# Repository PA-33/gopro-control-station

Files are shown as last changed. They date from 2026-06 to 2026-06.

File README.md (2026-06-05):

# GoPro Control Station

A complete remote control station for a GoPro Hero camera.

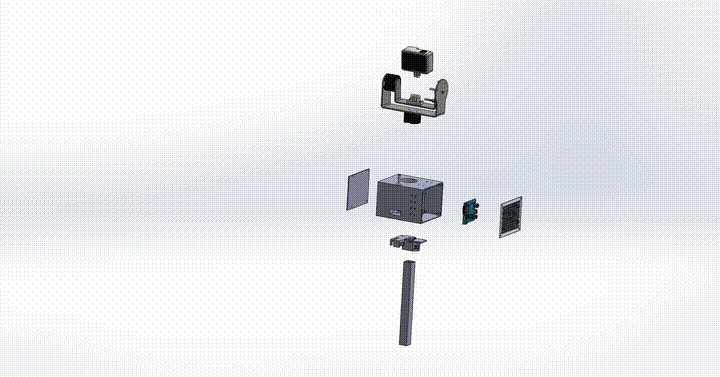
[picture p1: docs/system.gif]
System demo


The system combines a two-axis motorised mount (so the camera can be aimed
without touching it) with full remote control of the camera itself
(shutter, mode, gallery, live HDMI preview). Everything is driven by a
single ESP32-S3 board running closed-loop FOC for the motors, BLE for
the camera commands, and an HTTPS web server for the user interface.

## Features

- Two-axis motorised mount with absolute angular position
- Magnetic encoders for accurate, drift-free positioning
- Soft-limits with automatic end-stop calibration
- Stall protection with auto-recovery (re-centres the motor on re-enable)
- BLE control of the GoPro (shutter, mode, sleep, keep-alive)
- Wi-Fi proxy to the GoPro REST API (gallery, thumbnails, downloads)
- Browser-based live HDMI preview via a USB-C capture card
- Self-signed HTTPS server with embedded certificate
- Persistent configuration and calibration in NVS
- Status LED strip for camera, motors, recording state and battery

The user interacts with the system through two parallel channels:

- **Physical panel** — five buttons (M1+, M1-, M2+, M2-, shutter) and a
  7-LED status strip.
- **Web interface** — served on the station's own Wi-Fi access point:
  control, gallery, live HDMI preview and configuration in a
  mobile-friendly UI.

## Repository layout

```
gopro-control-station/
├── platformio.ini              PlatformIO build configuration
├── README.md
├── LICENSE
│
├── src/                        Firmware sources (Arduino + ESP-IDF)
│   ├── bridge_main.cpp         setup() / loop() / status LEDs
│   ├── bridge_foc.cpp/.h       motor control, buttons, calibration
│   ├── bridge_current.cpp/.h   current sensing + stall detection
│   ├── bridge_ble.cpp/.h       NimBLE client (OpenGoPro)
│   ├── bridge_wifi.cpp/.h      Wi-Fi AP + STA + watchdog
│   ├── bridge_https.cpp/.h     TLS web server + REST proxy
│   ├── bridge_server.cpp/.h    plain HTTP (cert download only)
│   ├── bridge_config.cpp/.h    persistent configuration (NVS)
│   ├── bridge_led.h            LED constants
│   └── ssl_cert.h              embedded TLS certificate (auto-generated)
│
├── data/
│   └── index.html              single-page web UI (served from LittleFS)
│
├── certs/                      TLS certificate + regeneration toolchain
│   ├── bridge_cert.pem
│   ├── bridge_key.pem
│   ├── openssl.cnf
│   ├── generate.bat            Windows: regenerate cert + key + header
│   └── make_header.py          convert PEM into src/ssl_cert.h
│
├── hardware/
│   ├── cad/
│   │   ├── source/             CAD source files
│   │   └── exports/            exported 3D-printable files
│   └── kicad/
│       ├── gimbal_driver_board/ electrical schematic + PCB sources
│       └── exports/            generated manufacturing files
│
└── docs/
    ├── user_manual.pdf           end-user manual
    └── Mode_d_emploi.pdf         end-user manual (French)
```

## Quick start

### 1. Build and flash the firmware

```bash
# Firmware
pio run -e esp32-s3-bridge -t upload

# Web UI (LittleFS image)
pio run -e esp32-s3-bridge -t uploadfs

# Watch the boot log
pio device monitor -e esp32-s3-bridge
```

A clean first boot prints, in order: PCF8574 ready, FOC init OK x2,
Wi-Fi AP up, BLE connected to the camera, HTTPS server started, Wi-Fi
STA connected to the GoPro. See `docs/repport.tex` §5.5 for the
reference serial log.

### 2. Connect

1. Join the Wi-Fi network `GoPro-Bridge` (default password `gopro1234`).
2. Open `https://192.168.4.1` in a browser.
3. Accept the security warning, or download the certificate from the
   *Config* tab and install it to make the warning go away.

### 3. Adapt to your own GoPro

No source edit is required. After the first boot, go to the *Config* tab
in the web UI, replace the GoPro Wi-Fi SSID and password with the ones
printed on your camera (*Connections / Connect Device / GoPro App*),
*Save*, and reboot.

## Documentation

- **`docs/mode_emploi.tex`** — end-user manual (French). Buttons, LEDs,
  web interface, calibration procedure.
- **`hardware/cad/`** — CAD sources and exports for the mechanical
  parts. Print settings and assembly order are documented in §3 of the
  report.
- **`hardware/kicad/`** — full electrical schematic and PCB project. The pin
  assignments are also reproduced in §4 of the report and are
  hard-coded in the firmware (see `src/bridge_foc.cpp`).

## Regenerating the TLS certificate

The repository ships with a self-signed development certificate that
works out of the box. For any deployment where the local network is not
trusted, regenerate it:

```bash
cd certs
generate.bat            # Windows
# POSIX equivalent: see docs/repport.tex Appendix D
```

Then re-flash the firmware. Every client that already trusted the
previous certificate has to install the new one (web UI, *Config* tab).

## Hardware overview

- **MCU**: ESP32-S3 (`esp32-s3-devkitc-1`), 8 MB flash, no PSRAM.
- **Motors**: 2x BLDC (11 pole pairs), each driven by a DRV8313.
- **Encoders**: 2x AS5048A magnetic absolute encoders (SPI / HSPI bus).
- **Buttons**: 5x momentary, multiplexed through a PCF8574T (I2C).
- **Current sense**: 2x INA180A1 with 50 mOhm shunts, read on ADC2.
- **Indicators**: WS2815 strip, 7 LEDs.
- **Camera**: GoPro Hero (any model compatible with the OpenGoPro BLE
  specification) with the official Media Mod for HDMI output.
- **HDMI capture**: any UVC-class USB-C card (UGREEN 15389 is
  auto-selected by the web UI).

## License

This project is released under the [MIT License](LICENSE). You can use,
modify and redistribute it freely, including for commercial purposes,
provided that the copyright notice and the license text are kept.

## Acknowledgements

Built on top of [SimpleFOC](https://docs.simplefoc.com/),
[NimBLE-Arduino](https://github.com/h2zero/NimBLE-Arduino),
[ESPAsyncWebServer](https://github.com/mathieucarbou/ESPAsyncWebServer),
and the [pioarduino fork](https://github.com/pioarduino/platform-espressif32)
of `platform-espressif32`. Camera control follows the
[OpenGoPro](https://gopro.github.io/OpenGoPro/) specification.

## Context

This project was developed by Pierre Adamini and Florian Klein as part of
the Assistive Technology Challenge at EPFL (2026).

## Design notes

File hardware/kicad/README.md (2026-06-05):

# KiCad project

Put the full KiCad source project here:

- `*.kicad_pro`
- `*.kicad_sch`
- `*.kicad_pcb`

Optional, only if you create local libraries later:

- `symbols/` for custom symbol libraries
- `footprints/` for custom footprint libraries

Use `exports/` for generated outputs only:

- Gerbers
- drill files
- PDF schematics
- BOM / pick-and-place files

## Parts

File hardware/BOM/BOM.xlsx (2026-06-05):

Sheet: Pièces usinées
PIÈCES USINÉES — Bill of Materials
Pièces imprimées 3D
Pièce | Quantité | Matériau
support_gopro | 1 | TPU | #VALUE!
limite | 2 | PLA/PETG | #VALUE!
casing | 1 | PLA/PETG | #VALUE!
grille_aeration | 1 | PLA/PETG | #VALUE!
couvercle_batterie | 1 | PLA/PETG | #VALUE!
adaptateur_casing_barre | 1 | PETG | #VALUE!
bearing support | 1 | PLA/PETG | #VALUE!
Chaise manuelle
Pièce | Quantité | Matériau
adaptateur_vertical | 1 | PETG | #VALUE!
adaptateur_horizontal | 1 | PETG | #VALUE!
Chaise motorisée
Pièce | Quantité | Matériau
adaptateur_chaise_motorisee | 1 | PETG | #VALUE!
Table
Pièce | Quantité | Matériau
pied_table | 1 | PLA/PETG | #VALUE!
Pièces découpées laser / PETG 100% remplissage
Pièce | Quantité | Matériau
support_gopro_int | 1 | Alu/PETG | #VALUE!
support_gopro_ext | 1 | Alu/PETG | #VALUE!

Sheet: BOM_PCB
PCB BILL OF MATERIALS
Reference | Qty | Value | DNP | Excl. Board | Footprint | Datasheet | URL Mouser
C1,C3 | 2 | 10uF |  |  | Capacitor_SMD:C_0805_2012Metric_Pad1.18x1.45mm_HandSolder | ~ | https://www.mouser.ch/ProductDetail/Murata-Electronics/GRM21BR61C106KE15L?qs=vS1sKHMaE9UZ7Oz%252BS7dCHg%3D%3D
C2,C4,C5,C8,C9,C11,C12,C13,C18,C19,C21,C22 | 12 | 100nF |  |  | Capacitor_SMD:C_0805_2012Metric_Pad1.18x1.45mm_HandSolder | ~ | https://www.mouser.ch/ProductDetail/KEMET/C0805C104K5RACTU?qs=ED%252B2xvMfDz1vOybjYDNIsA%3D%3D
C6,C16 | 2 | 10nF |  |  | Capacitor_SMD:C_0805_2012Metric_Pad1.18x1.45mm_HandSolder | ~ | https://www.mouser.ch/c/passive-components/capacitors/ceramic-capacitors/mlccs-multilayer-ceramic-capacitors/multilayer-ceramic-capacitors-mlcc-smd-smt/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
C7,C17 | 2 | 470nF |  |  | Capacitor_SMD:C_0805_2012Metric_Pad1.18x1.45mm_HandSolder | ~ | https://www.mouser.ch/c/passive-components/capacitors/ceramic-capacitors/mlccs-multilayer-ceramic-capacitors/multilayer-ceramic-capacitors-mlcc-smd-smt/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
C10,C20 | 2 | 100uF |  |  | Capacitor_THT:CP_Radial_D10.0mm_P5.00mm | ~ | https://www.mouser.ch/ProductDetail/Panasonic/ECA-1CM101?qs=fcM5arftASsgt75dWf2hGA%3D%3D
C14,C15 | 2 | 470uF |  |  | Capacitor_THT:CP_Radial_D10.0mm_P5.00mm | ~ | https://www.mouser.ch/c/passive-components/capacitors/aluminum-electrolytic-capacitors/aluminum-electrolytic-capacitors-radial-leaded/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
D1 | 1 | 1N5819HW-7-F |  |  | LED_SMD:LED_0805_2012Metric_Pad1.15x1.40mm_HandSolder | https://datasheet.lcsc.com/lcsc/2204281430_Guangdong-Hottech-1N5819WS_C191023.pdf | https://www.mouser.ch/ProductDetail/Diodes-Incorporated/1N5819HW-7-F?qs=NQ47qNm99eDyWTEd07miYA%3D%3D
D2 | 1 | 1N5819WS |  |  | LED_SMD:LED_0805_2012Metric_Pad1.15x1.40mm_HandSolder | https://datasheet.lcsc.com/lcsc/2204281430_Guangdong-Hottech-1N5819WS_C191023.pdf | https://www.mouser.ch/c/semiconductors/discrete-semiconductors/diodes-rectifiers/schottky-diodes-rectifiers/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
D3 | 1 | SS34 |  |  | Diode_SMD:D_SMA_Handsoldering | https://www.vishay.com/docs/88751/ss32.pdf | https://www.mouser.ch/ProductDetail/onsemi-Fairchild/SS34?qs=sGAEpiMZZMueQxo7L%2FBPyPQxv%252BkbJV2b
D4 | 1 | LED |  |  | LED_SMD:LED_0805_2012Metric_Pad1.15x1.40mm_HandSolder | ~ | https://www.mouser.ch/c/optoelectronics/leds/standard-leds-smd/?q=LED+0805+vert
H1,H2 | 2 | MountingHole |  |  | MountingHole:MountingHole_2.2mm_M2 | ~
J1 | 1 | USB_C_Receptacle_USB2.0_16P |  |  | Connector_USB:USB_C_Receptacle_HRO_TYPE-C-31-M-12 | https://www.usb.org/sites/default/files/documents/usb_type-c.zip | https://www.mouser.ch/c/connectors/usb-connectors/?q=USB-C+receptacle+16P
J2,J10 | 2 | Motor |  |  | Connector_JST:JST_XH_B3B-XH-A_1x03_P2.50mm_Vertical | ~ | https://www.mouser.ch/c/connectors/rectangular-connectors/headers-male-pins/?q=B3B-XH-A
J3 | 1 | Encoder1 |  |  | Connector_JST:JST_SH_BM06B-SRSS-TB_1x06-1MP_P1.00mm_Vertical | ~ | https://www.mouser.ch/c/connectors/rectangular-connectors/headers-male-pins/?q=BM06B-SRSS-TB
J4 | 1 | Conn_01x09_Socket |  |  | Connector_JST:JST_GH_BM09B-GHS-TBT_1x09-1MP_P1.25mm_Vertical | ~ | https://www.mouser.ch/c/connectors/rectangular-connectors/headers-male-pins/?q=BM09B-GHS-TBT
J5 | 1 | Encoder2 |  |  | Connector_JST:JST_SH_BM06B-SRSS-TB_1x06-1MP_P1.00mm_Vertical | ~ | https://www.mouser.ch/c/connectors/rectangular-connectors/headers-male-pins/?q=BM06B-SRSS-TB
J6 | 1 | I2C |  |  | Connector_JST:JST_SH_BM04B-SRSS-TB_1x04-1MP_P1.00mm_Vertical | ~ | https://www.mouser.ch/c/connectors/rectangular-connectors/headers-male-pins/?q=BM04B-SRSS-TB
J7 | 1 | LED |  |  | Connector_JST:JST_PH_B3B-PH-K_1x03_P2.00mm_Vertical | ~ | https://www.mouser.ch/c/connectors/rectangular-connectors/headers-male-pins/?q=B3B-PH-K
J8 | 1 | Bat in |  |  | Connector_Wire:SolderWire-1sqmm_1x02_P7.8mm_D1.4mm_OD3.9mm | ~ | https://www.mouser.ch/c/connectors/terminals/solder-lugs/?q=solder+wire+2pin
J9 | 1 | 3v3 out |  |  | Connector_Wire:SolderWire-0.5sqmm_1x02_P4.8mm_D0.9mm_OD2.3mm | ~ | https://www.mouser.ch/c/connectors/terminals/solder-lugs/?q=solder+wire+2pin
L1 | 1 | 33uH |  |  | Inductor_SMD:L_1008_2520Metric_Pad1.43x2.20mm_HandSolder | ~ | https://www.mouser.ch/ProductDetail/Bourns/SDR0604-330KL?qs=xrpI9KL%2FXvt31%2F8W4eBsNg%3D%3D
LS1 | 1 | PS1240P02BT |  |  | PS1240P02BT:XDCR_PS1240P02BT |  | https://www.mouser.ch/ProductDetail/TDK/PS1240P02BT?qs=d7g9p1yFhWaZXSY9MjKMkw%3D%3D
Q1 | 1 | AO3400A |  |  | Package_TO_SOT_SMD:SOT-23_Handsoldering | http://www.aosmd.com/pdfs/datasheet/AO3400A.pdf | https://www.mouser.ch/c/semiconductors/discrete-semiconductors/transistors/mosfets/?q=AO3400A
R1,R2 | 2 | 5k1 |  |  | Resistor_SMD:R_0805_2012Metric_Pad1.20x1.40mm_HandSolder | ~ | https://www.mouser.ch/ProductDetail/YAGEO/RC0805FR-075K11L?qs=GWlJ5nlKA9Kjt4Lvy7ebqg%3D%3D
R3,R4,R5,R6,R7,R8,R9,R11,R13,R17,R18,R19,R21 | 13 | 10k |  |  | Resistor_SMD:R_0805_2012Metric_Pad1.20x1.40mm_HandSolder | ~ | https://www.mouser.ch/ProductDetail/YAGEO/RC0805FR-0710KL?qs=7bY8808IzHq6vrU3BeiiYw%3D%3D
R10,R20 | 2 | 0.05 |  |  | Resistor_SMD:R_1210_3225Metric_Pad1.30x2.65mm_HandSolder | ~ | https://www.mouser.ch/c/passive-components/resistors/current-sense-resistors/current-sense-resistors-smd/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
R12 | 1 | 100 |  |  | Resistor_SMD:R_0805_2012Metric_Pad1.20x1.40mm_HandSolder | ~ | https://www.mouser.ch/ProductDetail/YAGEO/RC0805FR-07100RL
R14 | 1 | 100k |  |  | Resistor_SMD:R_0805_2012Metric_Pad1.20x1.40mm_HandSolder | ~ | https://www.mouser.ch/c/passive-components/resistors/film-resistors/thick-film-resistors-smd/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
R15 | 1 | 33k |  |  | Resistor_SMD:R_0805_2012Metric_Pad1.20x1.40mm_HandSolder | ~ | https://www.mouser.ch/c/passive-components/resistors/film-resistors/thick-film-resistors-smd/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
R16 | 1 | 1k |  |  | Resistor_SMD:R_0805_2012Metric_Pad1.20x1.40mm_HandSolder | ~ | https://www.mouser.ch/ProductDetail/YAGEO/RC0805FR-071KL?qs=1ogmaHw32WJjeGY0DHXakQ%3D%3D
SW1,SW2 | 2 | SW_MEC_5G |  |  | bouton_smd:bouton_smd_kit_botanique | http://www.apem.com/int/index.php?controller=attachment&id_attachment=488 | https://www.mouser.ch/c/electromechanical/switches/tactile-switches/?q=MEC+5G+SMD
U1 | 1 | USBLC6-2SC6 |  |  | Package_TO_SOT_SMD:SOT-23-6 | https://www.st.com/resource/en/datasheet/usblc6-2.pdf | https://www.mouser.ch/ProductDetail/STMicroelectronics/USBLC6-2SC6?qs=po45yt2pPpu%2FhNIlwQdTlg%3D%3D
U2 | 1 | ESP32-S3-WROOM-1 |  |  | PCM_Espressif:ESP32-S3-WROOM-1_homemade | https://www.espressif.com/sites/default/files/documentation/esp32-s3-wroom-1_wroom-1u_datasheet_en.pdf | https://www.mouser.ch/ProductDetail/Espressif-Systems/ESP32-S3-WROOM-1-N4?qs=Li%2BoUPsLEnsO%2FkiJOUK0FQ%3D%3D
U3,U7 | 2 | DRV8313PWP |  |  | DRV8313PWP:SOP65P640X120-29N |  | https://www.mouser.ch/ProductDetail/Texas-Instruments/DRV8313PWP?qs=aQEsdMNF%2FMxhZX%2FpCdLUTw%3D%3D
U4,U8 | 2 | INA180A1 |  |  | Package_TO_SOT_SMD:SOT-23-5_HandSoldering | http://www.ti.com/lit/ds/symlink/ina180.pdf | https://www.mouser.ch/ProductDetail/Texas-Instruments/INA180A1IDBVT?qs=5aG0NVq1C4xFxtYnO6UmMg%3D%3D
U5 | 1 | PCF8574T |  |  | Package_SO:SOIC-16W_7.5x10.3mm_P1.27mm | http://www.nxp.com/docs/en/data-sheet/PCF8574_PCF8574A.pdf | https://www.mouser.ch/ProductDetail/NXP-Semiconductors/PCF8574T-3512?qs=LOCUfHb8d9twdQnCFHYQdg%3D%3D
U6 | 1 | LM2596S-3.3 |  |  | Package_TO_SOT_SMD:TO-263-5_TabPin3 | http://www.ti.com/lit/ds/symlink/lm2596.pdf | https://www.mouser.ch/ProductDetail/Texas-Instruments/LM2596S-3.3?qs=X1J7HmVL2ZHnG50G34wg0g%3D%3D

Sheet: Autres composants
AUTRES COMPOSANTS — Bill of Materials
Composant | Quantité | Référence | Lien
PCB | 1 | Custom PCB but spares ones given | https://jlcpcb.com/fr/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
gimbal motor | 2 | Motor Gimbal iPower GM3506 with encoder | https://iflight-rc.eu/fr-fr/products/ipower-gm3506-gimbal-motor-with-encoder
hdmi flex cable | 1
micro HDMI male | 1 | WaveShare Micro HDMI mâle vertical coudé à 90 | https://www.digitec.ch/fr/s1/product/waveshare-micro-hdmi-male-vertical-coude-a-90-cable-video-37769133
HDMI female | 1 | WaveShare HDMI femelle mâle horizontal | https://www.digitec.ch/fr/s1/product/waveshare-hdmi-femelle-male-horizontal-cable-video-37769132
HDMI cable | 1 | WaveShare 0.5m DIY Câble HDMI FFC | https://www.digitec.ch/fr/s1/product/waveshare-05m-diy-cable-hdmi-ffc-050-m-cable-video-37769134
Mediamod | 1 | GoPro media mod | https://www.digitec.ch/fr/s1/product/gopro-media-mod-camera-daction-accessoires-13875827
HDMI capture | 1 | Ugreen HD HDMI to USB-A/USB-C Video Capture Card / Adapter - Gray | https://www.galaxus.ch/fr/s1/product/ugreen-hd-hdmi-to-usb-ausb-c-video-capture-card-adapter-gray-cable-usb-63898220
ventouses | 2 | PhoneLook Support téléphone universel ventouse avec fixation autocollante en silicone | https://www.galaxus.ch/fr/s1/product/phonelook-support-telephone-universel-ventouse-avec-fixation-autocollante-en-silicone-support-pour-s-61308671
barre aluminium | 1 | barre aluminium 20*20*280
barre aluminium | 1 | barre aluminium 20*20*550

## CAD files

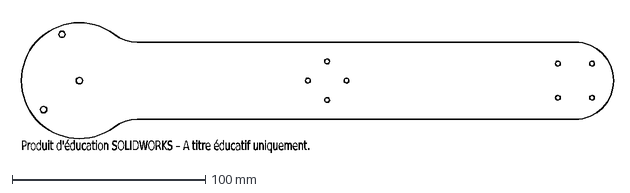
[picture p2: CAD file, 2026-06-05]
hardware/cad/exports/assemblage/Etat déplié - GoPro_support_ext.DXF
Produit d'éducation SOLIDWORKS – A titre éducatif uniquement.

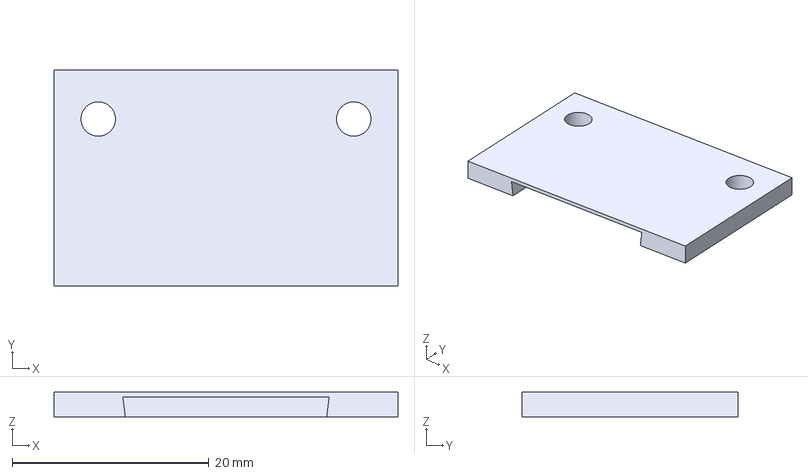
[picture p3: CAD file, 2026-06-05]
hardware/cad/exports/supp_boutons/cache_vga_top.3MF
35.0 x 22.0 x 2.50 mm

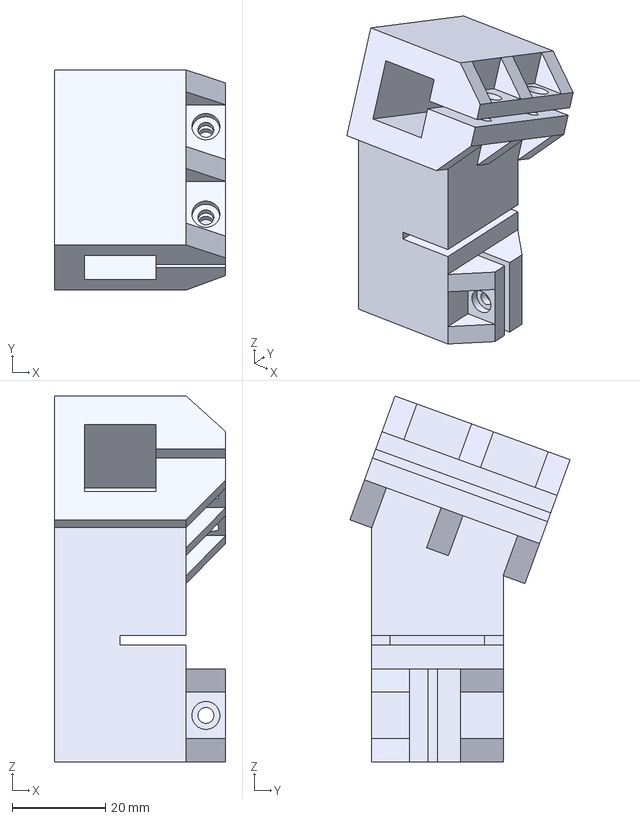
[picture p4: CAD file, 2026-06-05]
hardware/cad/exports/support_chaise/chaise_manuelle/adaptateur_20deg.3MF
36.8 x 47.3 x 78.6 mm

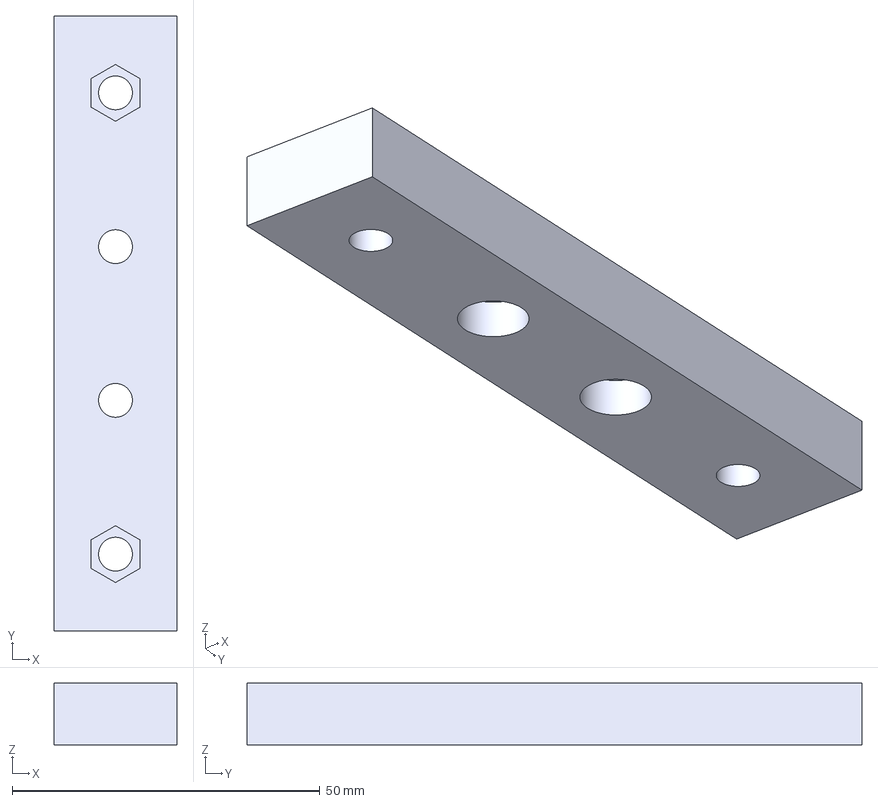
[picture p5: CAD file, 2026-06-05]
hardware/cad/exports/support_chaise/chaise_motorisee/adaptateur_chaise_e.3MF
20.0 x 100.0 x 10.0 mm

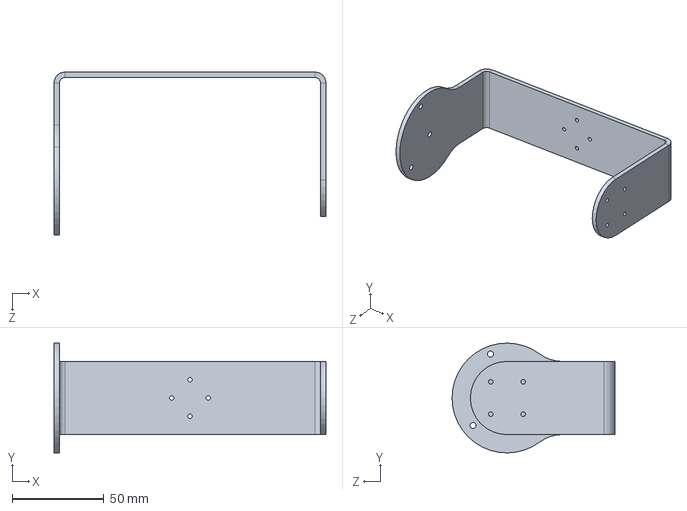
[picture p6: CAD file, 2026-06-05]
hardware/cad/source/assemblage/GoPro_support_ext.SLDPRT
148.6 x 60.0 x 89.0 mm

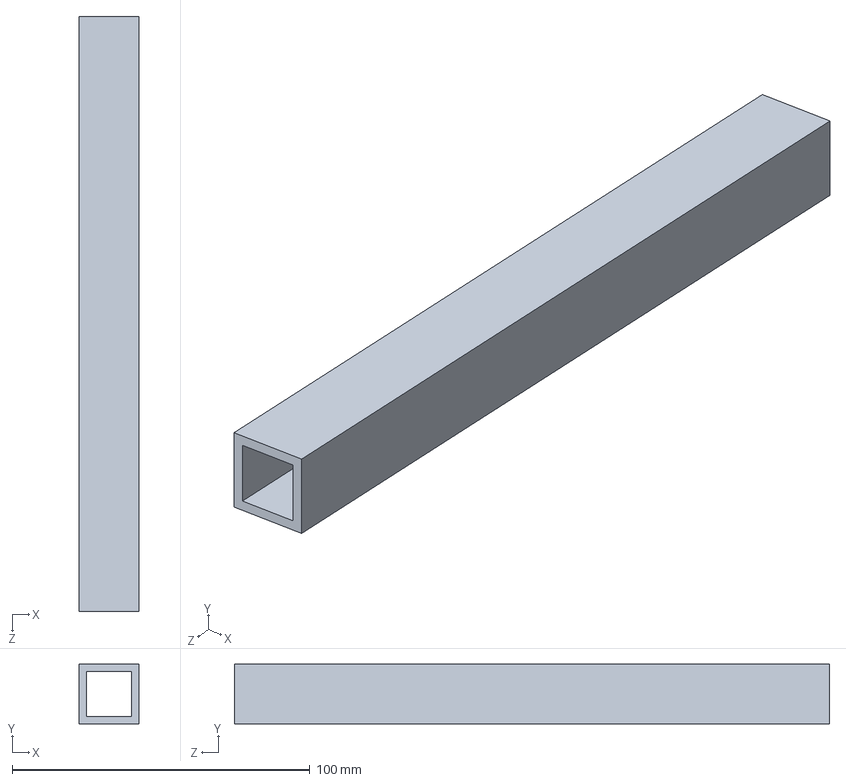
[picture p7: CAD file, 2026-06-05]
hardware/cad/source/support_chaise/barre.SLDPRT
20.0 x 20.0 x 200.0 mm

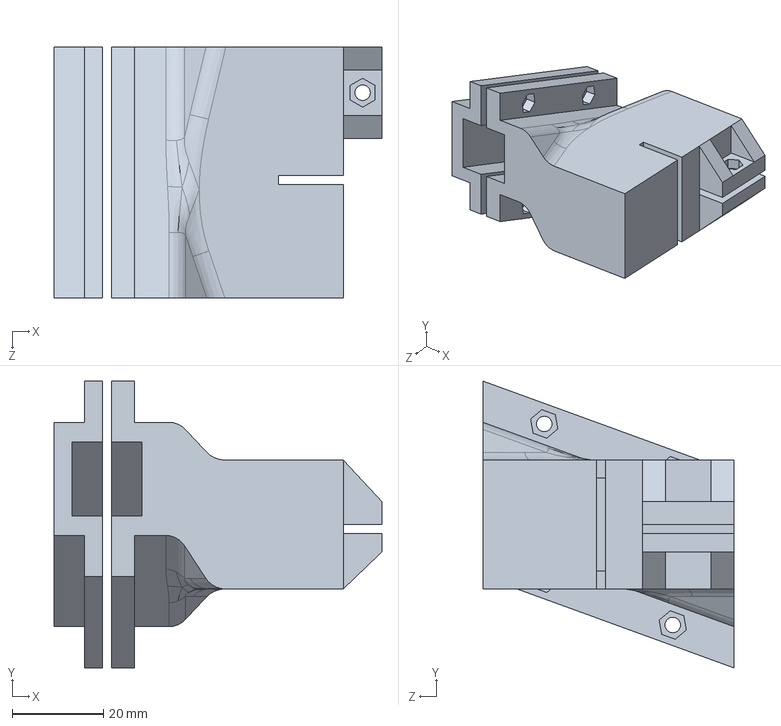
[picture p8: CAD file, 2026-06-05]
hardware/cad/source/support_chaise/chaise_manuelle/adaptateur_vertical.SLDPRT
71.9 x 62.9 x 55.0 mm

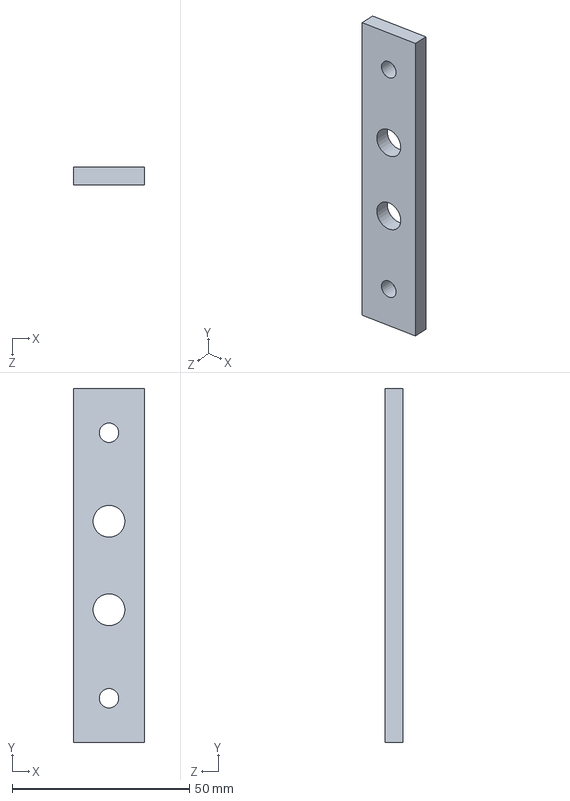
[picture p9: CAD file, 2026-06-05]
hardware/cad/source/support_chaise/chaise_motorisee/adaptateur_chaise_motorisee.SLDPRT
20.0 x 100.0 x 5.00 mm

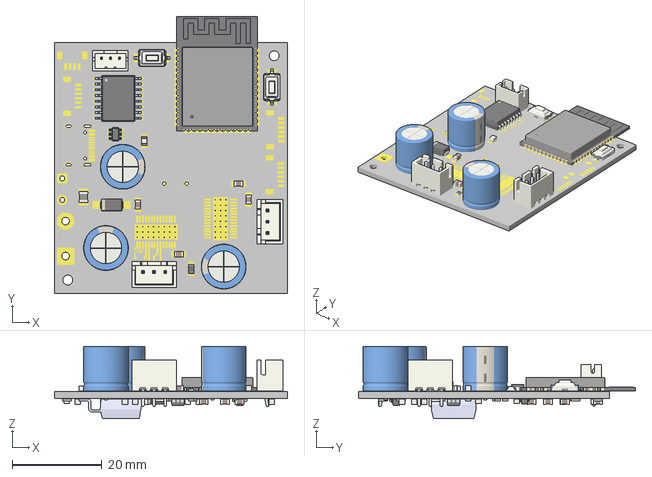
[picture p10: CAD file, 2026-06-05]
hardware/kicad/exports/gimbal_driver_board/gimbal_driver_board.3MF
52.0 x 61.8 x 16.1 mm

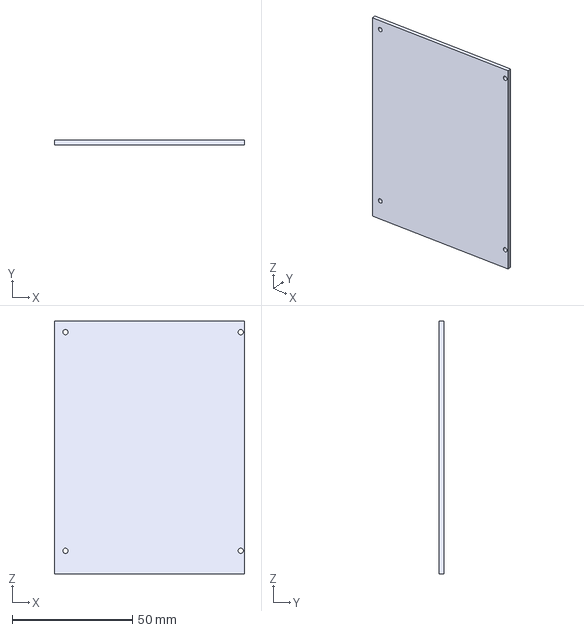
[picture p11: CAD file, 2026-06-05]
hardware/cad/exports/assemblage/couvercle_batterie.3MF
79.0 x 2.00 x 105.0 mm

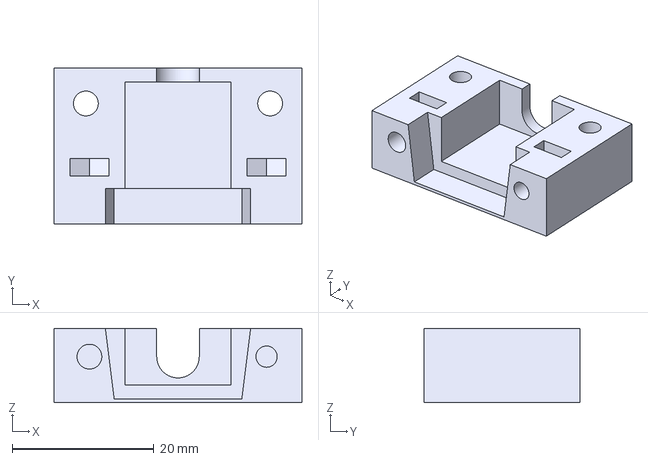
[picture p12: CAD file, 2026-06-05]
hardware/cad/exports/supp_boutons/cache vga_bottom.3MF
35.0 x 22.0 x 10.5 mm

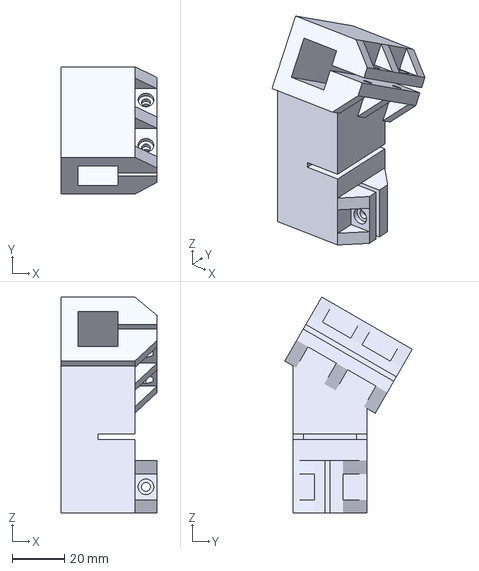
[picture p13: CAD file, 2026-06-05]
hardware/cad/exports/support_chaise/chaise_manuelle/adaptateur_30deg.3MF
36.8 x 48.8 x 82.7 mm

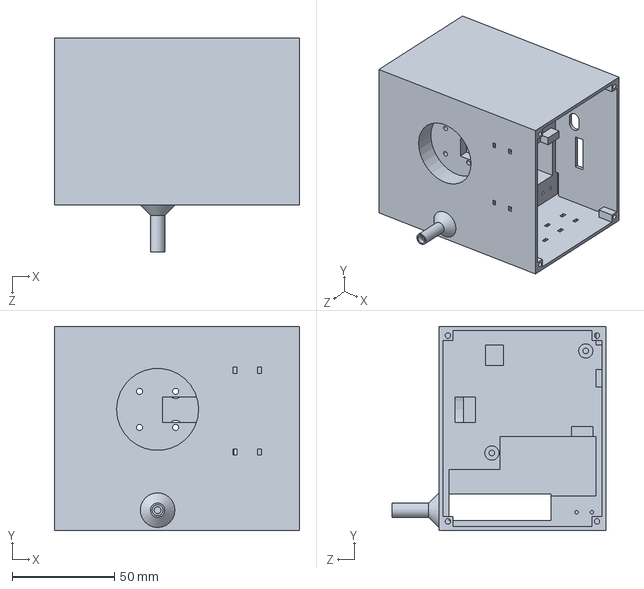
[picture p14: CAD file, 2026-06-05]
hardware/cad/source/assemblage/casing.SLDPRT
120.0 x 100.0 x 105.0 mm

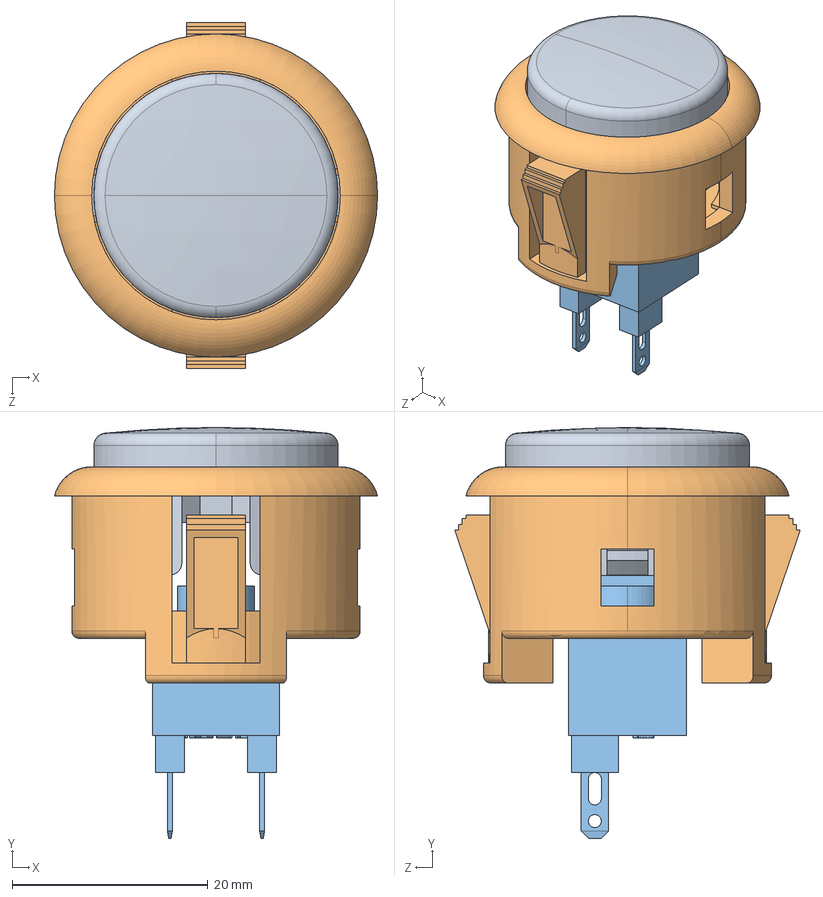
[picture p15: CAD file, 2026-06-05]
hardware/cad/source/supp_boutons/sanwa obsf-30-g.STEP
33.0 x 42.0 x 35.3 mm
top_cap
base
microswitch

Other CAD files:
hardware/cad/source/supp_boutons/Assemblage_ButtonV2.SLDASM
hardware/cad/source/support_chaise/chaise_manuelle/adaptateur.SLDPRT
hardware/cad/source/support_chaise/pied table.SLDPRT
hardware/cad/source/assemblage/GM3506 With Encoder.step
hardware/cad/exports/assemblage/Bearing_support.3MF
hardware/cad/exports/assemblage/GoPro_support.3MF
hardware/cad/exports/assemblage/GoPro_support_ext.3MF
hardware/cad/exports/assemblage/adaptateur_casing_barre.3MF
hardware/cad/exports/assemblage/casing.3MF
hardware/cad/exports/assemblage/grille aeration.3MF
hardware/cad/exports/assemblage/limites.3MF
hardware/cad/exports/assemblage/support_gopro.3MF
hardware/cad/exports/supp_boutons/Assemblage_ButtonV2.3MF
hardware/cad/exports/supp_boutons/button_bottom.3MF
hardware/cad/exports/supp_boutons/button_top.3MF
hardware/cad/exports/support_chaise/chaise_manuelle/adaptateur.3MF
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

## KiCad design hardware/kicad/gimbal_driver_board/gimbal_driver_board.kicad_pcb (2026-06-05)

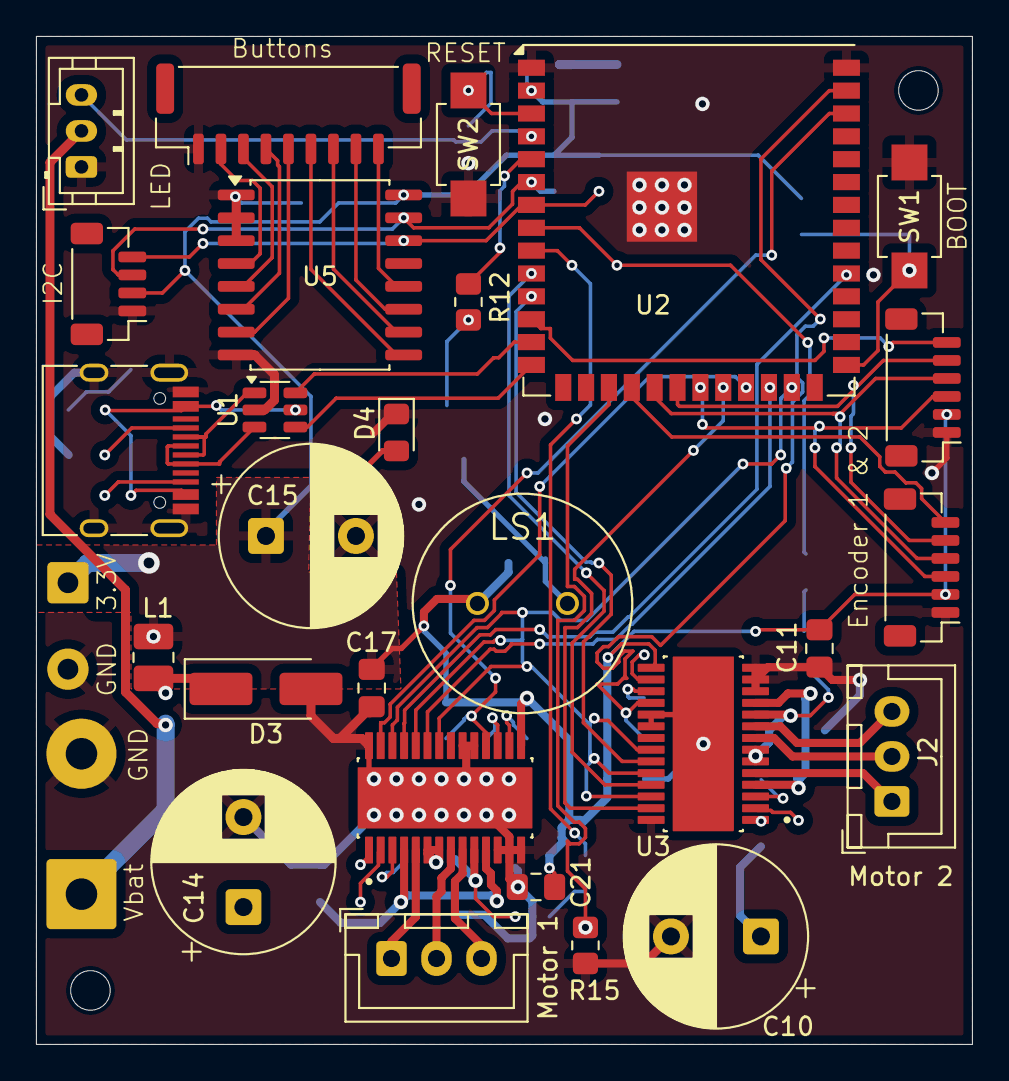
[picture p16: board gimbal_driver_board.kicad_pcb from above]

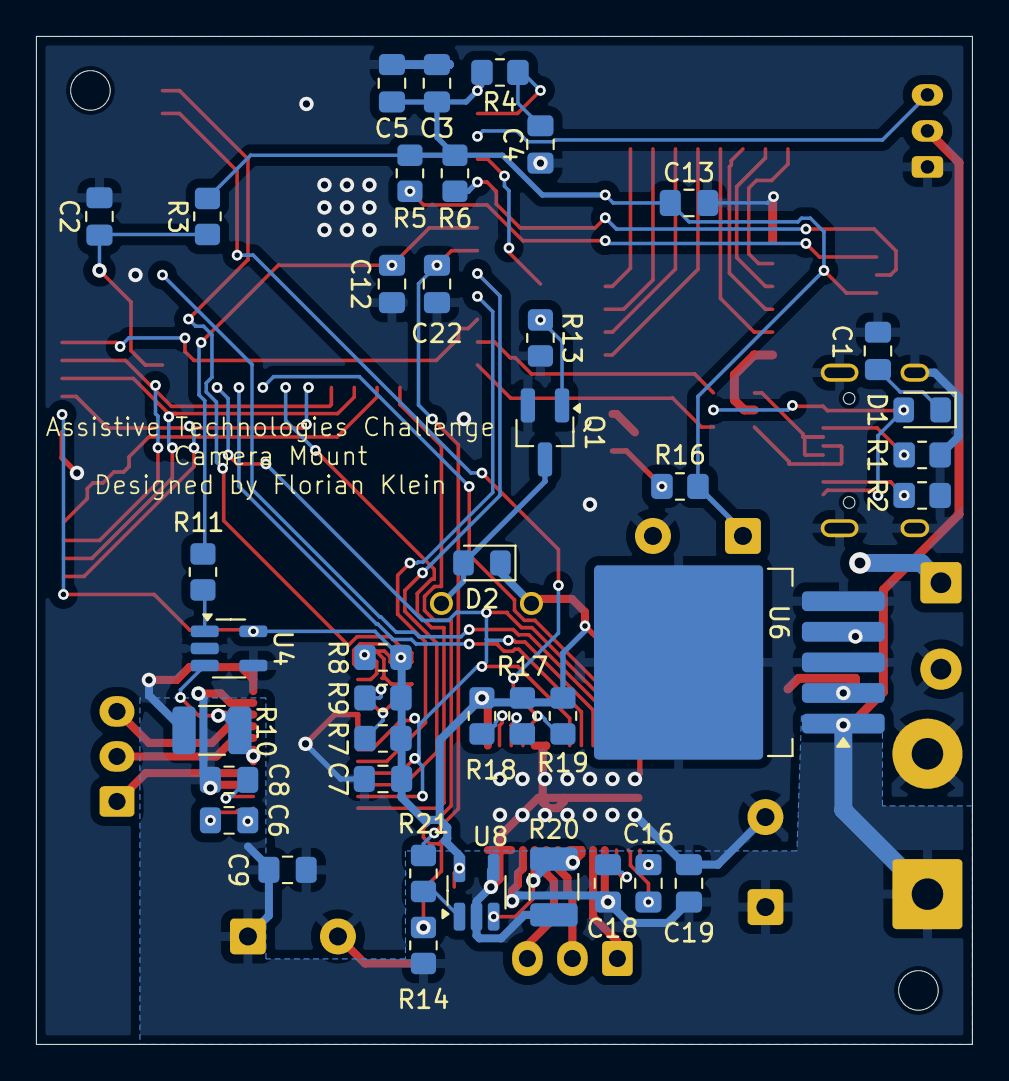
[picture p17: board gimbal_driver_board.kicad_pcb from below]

Board: 2 copper layers, 52.0 x 56.0 mm, 71 parts (40 on the bottom side), 66 nets.

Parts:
C1, C3: 10uF; C_0805_2012Metric_Pad1.18x1.45mm_HandSolder
C2, C4, C5, C8, C9, C11, C12, C13, C18, C19, C21, C22: 100nF; C_0805_2012Metric_Pad1.18x1.45mm_HandSolder
C6, C16: 10nF; C_0805_2012Metric_Pad1.18x1.45mm_HandSolder
C7, C17: 470nF; C_0805_2012Metric_Pad1.18x1.45mm_HandSolder
C10: 100uF; CP_Radial_D10.0mm_P5.00mm
C14, C15: 470uF; CP_Radial_D10.0mm_P5.00mm
D1: 1N5819HW-7-F; LED_0805_2012Metric_Pad1.15x1.40mm_HandSolder
D2: 1N5819WS; LED_0805_2012Metric_Pad1.15x1.40mm_HandSolder
D3: SS34; D_SMA_Handsoldering
D4: LED; LED_0805_2012Metric_Pad1.15x1.40mm_HandSolder
H1, H2: MountingHole; MountingHole_2.2mm_M2
J1: USB_C_Receptacle_USB2.0_16P; USB_C_Receptacle_HRO_TYPE-C-31-M-12
J2, J10: Motor; JST_XH_B3B-XH-A_1x03_P2.50mm_Vertical
J3: Encoder1; JST_SH_BM06B-SRSS-TB_1x06-1MP_P1.00mm_Vertical
J4: Conn_01x09_Socket; JST_GH_BM09B-GHS-TBT_1x09-1MP_P1.25mm_Vertical
J5: Encoder2; JST_SH_BM06B-SRSS-TB_1x06-1MP_P1.00mm_Vertical
J6: I2C; JST_SH_BM04B-SRSS-TB_1x04-1MP_P1.00mm_Vertical
J7: LED; JST_PH_B3B-PH-K_1x03_P2.00mm_Vertical
J8: Bat in; SolderWire-1sqmm_1x02_P7.8mm_D1.4mm_OD3.9mm
J9: 3v3 out; SolderWire-0.5sqmm_1x02_P4.8mm_D0.9mm_OD2.3mm
L1: 33uH; L_1008_2520Metric_Pad1.43x2.20mm_HandSolder
LS1: PS1240P02BT; XDCR_PS1240P02BT
Q1: AO3400A; SOT-23_Handsoldering
R1, R2: 5k1; R_0805_2012Metric_Pad1.20x1.40mm_HandSolder
R3, R4, R5, R6, R7, R8, R9, R11, R13, R17, R18, R19, R21: 10k; R_0805_2012Metric_Pad1.20x1.40mm_HandSolder
R10, R20: 0.05; R_1210_3225Metric_Pad1.30x2.65mm_HandSolder
R12: 100; R_0805_2012Metric_Pad1.20x1.40mm_HandSolder
R14, R15: R; R_0805_2012Metric_Pad1.20x1.40mm_HandSolder
R16: 1k; R_0805_2012Metric_Pad1.20x1.40mm_HandSolder
SW1, SW2: SW_MEC_5G; bouton_smd_kit_botanique
U1: USBLC6-2SC6; SOT-23-6
U2: ESP32-S3-WROOM-1; ESP32-S3-WROOM-1_homemade
U3, U7: DRV8313PWP; SOP65P640X120-29N
U4, U8: INA180A1; SOT-23-5_HandSoldering
U5: PCF8574T; SOIC-16W_7.5x10.3mm_P1.27mm
U6: LM2596S-3.3; TO-263-5_TabPin3

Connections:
1IN1: U2.22 (GPIO14/TOUCH14/ADC2_CH3/FSPIWP/FSPIDQS/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), U3.27 (IN1)
1IN2: U2.10 (GPIO17/U1TXD/ADC2_CH6), U3.25 (IN2)
1IN3: U2.11 (GPIO18/U1RXD/ADC2_CH7/CLK_OUT3), U3.23 (IN3)
2IN1: U2.23 (GPIO21), U7.27 (IN1)
2IN2: U2.31 (GPIO38/FSPIWP/SUBSPIWP), U7.25 (IN2)
2IN3: U2.24 (GPIO47/SPICLK_P/SUBSPICLK_P_DIFF), U7.23 (IN3)
+3.3V: C3.1, C5.1, C7.1, C11.1, C13.1, C15.1, C17.1, C21.1, D2.1 (K), J3.2, J5.2, J6.2, J9.1, L1.2, LS1.1, R3.2, R4.2, R5.1, R6.1, R7.1, R8.1, R9.2, R16.1, R17.1, R18.1, R19.2, U2.2 (3V3), U3.15 (V3P3), U4.5 (V+), U5.16 (VDD), U6.4 (FB), U7.15 (V3P3), U8.5 (V+)
ADC_bat: R14.2, R15.1, U2.17 (GPIO9/TOUCH9/ADC1_CH8/FSPIHD/SUBSPIHD)
Button0: J4.2, U5.4 (P0)
Button1: J4.3, U5.5 (P1)
Button2: J4.4, U5.6 (P2)
Button3: J4.5, U5.7 (P3)
Button4: J4.6, U5.9 (P4)
Button5: J4.7, U5.10 (P5)
Button6: J4.8, U5.11 (P6)
Button7: J4.9, U5.12 (P7)
Buzzer: R12.1, U2.5 (GPIO5/TOUCH5/ADC1_CH4)
CHIP_PU: C4.1, R4.1, SW2.3 (B), SW2.4 (B), U2.3 (EN)
CS1: J3.6, U2.18 (GPIO10/TOUCH10/ADC1_CH9/FSPICS0/FSPIIO4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)
CS2: J5.6, U2.12 (GPIO8/TOUCH8/ADC1_CH7/SUBSPICS1)
D+: U1.4 (I/O2), U2.14 (GPIO20/U1CTS/ADC2_CH9/CLK_OUT1/USB_D+)
D-: U1.6 (I/O1), U2.13 (GPIO19/U1RTS/ADC2_CH8/CLK_OUT2/USB_D-)
EN: U2.25 (GPIO48/SPICLK_N/SUBSPICLK_N_DIFF), U3.22 (EN3), U3.24 (EN2), U3.26 (EN1), U7.22 (EN3), U7.24 (EN2), U7.26 (EN1)
GND: C1.2, C2.2, C3.2, C4.2, C5.2, C7.2, C9.2, C10.2, C11.2, C12.2, C13.2, C14.2, C15.2, C17.2, C19.2, C21.2, C22.2, D3.2 (A), D4.1 (K), J1.A1 (GND), J1.A12 (GND), J1.B1 (GND), J1.B12 (GND), J1.S1 (SHIELD), J3.1, J4.1, J5.1, J6.1, J7.1, J8.2, J9.2, Q1.2 (S), R1.2, R2.2, R10.2, R13.2, R15.2, R20.2, SW1.1 (A), SW1.2 (A), SW2.1 (A), SW2.2 (A), U1.2 (GND), U2.1 (GND), U2.40 (GND), U2.41 (GND), U3.12 (COMPP), U3.13 (COMPN), U3.14 (GND), U3.19 (~COMPO), U3.20 (GND), U3.28 (GND), U3.29 (EXP), U4.2 (GND), U4.4 (-), U5.1 (A0), U5.2 (A1), U5.3 (A2), U5.8 (GND), U6.3 (GND), U6.5 (~ON/OFF), U7.12 (COMPP), U7.13 (COMPN), U7.14 (GND), U7.19 (~COMPO), U7.20 (GND), U7.28 (GND), U7.29 (EXP), U8.2 (GND), U8.4 (-)
GPIO0: C2.1, R3.1, SW1.3 (B), SW1.4 (B), U2.27 (GPIO0/BOOT)
I1: C12.1, R11.2, U2.8 (GPIO15/U0RTS/ADC2_CH4/XTAL_32K_P)
I2: C22.1, R21.2, U2.9 (GPIO16/U0CTS/ADC2_CH5/XTAL_32K_N)
LED: J7.3, U2.4 (GPIO4/TOUCH4/ADC1_CH3)
MISO: J3.3, J5.3, U2.21 (GPIO13/TOUCH13/ADC2_CH2/FSPIQ/FSPIIO7/S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)
MOSI: J3.4, J5.4, U2.19 (GPIO11/TOUCH11/ADC2_CH0/FSPID/FSPIIO5/S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)
unnamed: D1.2 (A), J1.A4 (VBUS), J1.A9 (VBUS), J1.B4 (VBUS), J1.B9 (VBUS), U1.5 (VBUS)
unnamed: C1.1, D1.1 (K)
unnamed: D2.2 (A), LS1.2, Q1.3 (D)
unnamed: D3.1 (K), L1.1, U6.2 (OUT)
unnamed: D4.2 (A), R16.2
unnamed: J1.A5 (CC1), R1.1
unnamed: J1.B5 (CC2), R2.1
unnamed: J1.A6 (D+), J1.B6 (D+), U1.3 (I/O2)
unnamed: J1.A7 (D-), J1.B7 (D-), U1.1 (I/O1)
unnamed: J2.1, U3.5 (OUT1)
unnamed: J2.2, U3.8 (OUT2)
unnamed: J2.3, U3.9 (OUT3)
unnamed: J10.1, U7.5 (OUT1)
unnamed: J10.2, U7.8 (OUT2)
unnamed: J10.3, U7.9 (OUT3)
unnamed: Q1.1 (G), R12.2, R13.1
unnamed: R11.1, U4.1
unnamed: R21.1, U8.1
unnamed: C6.2, U3.2 (CPH)
unnamed: C6.1, U3.1 (CPL)
unnamed: R10.1, U3.6 (PGND1), U3.7 (PGND2), U3.10 (PGND3), U4.3 (+)
unnamed: C8.1, U3.3 (VCP)
unnamed: R8.2, U3.16 (~RESET)
unnamed: R7.2, U3.17 (~SLEEP)
unnamed: C16.2, U7.2 (CPH)
unnamed: C16.1, U7.1 (CPL)
unnamed: R20.1, U7.6 (PGND1), U7.7 (PGND2), U7.10 (PGND3), U8.3 (+)
unnamed: C18.1, U7.3 (VCP)
unnamed: R18.2, U7.16 (~RESET)
unnamed: R17.2, U7.17 (~SLEEP)
SCL: J6.4, R5.2, U2.7 (GPIO7/TOUCH7/ADC1_CH6), U5.14 (SCL)
SCLK: J3.5, J5.5, U2.20 (GPIO12/TOUCH12/ADC2_CH1/FSPICLK/FSPIIO6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)
SDA: J6.3, R6.2, U2.6 (GPIO6/TOUCH6/ADC1_CH5), U5.15 (SDA)
VCC: C8.2, C9.1, C10.1, C14.1, C18.2, C19.1, J7.2, J8.1, R14.1, U3.4 (VM), U3.11 (VM), U6.1 (VIN), U7.4 (VM), U7.11 (VM)
nFT1: R9.1, U2.39 (GPIO1/TOUCH1/ADC1_CH0), U3.18 (~FAULT)
nFT2: R19.1, U2.38 (GPIO2/TOUCH2/ADC1_CH1), U7.18 (~FAULT)

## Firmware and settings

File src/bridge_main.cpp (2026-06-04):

/*M1:[251;320], M2[-265;-345]*/



#include <Arduino.h>
#include <LittleFS.h>
#include <Adafruit_NeoPixel.h>
#include "bridge_config.h"
#include "bridge_wifi.h"
#include "bridge_ble.h"
#include "bridge_foc.h"
#include "bridge_current.h"
#include "bridge_https.h"
// ESPAsyncWebServer / bridge_server retires : le serveur HTTP port 80
// bouffait ~20-30 ko de heap qui fragmentait le bloc max contigu sous le
// seuil mbedTLS. Le cert est maintenant servi via HTTPS (/cert.crt).

static BridgeConfig   cfg;

#ifndef BRIDGE_WS2815_PIN
#define BRIDGE_WS2815_PIN 4
#endif

#ifndef BRIDGE_WS2815_COUNT
#define BRIDGE_WS2815_COUNT 7
#endif

#ifndef BRIDGE_WS2815_BRIGHTNESS
#define BRIDGE_WS2815_BRIGHTNESS 80
#endif

#ifndef BRIDGE_WS2815_PIXEL_TYPE
#define BRIDGE_WS2815_PIXEL_TYPE (NEO_RGB + NEO_KHZ800)
#endif

#ifndef BRIDGE_BAT_ADC_PIN
#define BRIDGE_BAT_ADC_PIN 9
#endif

#ifndef BRIDGE_BAT_DIVIDER
#define BRIDGE_BAT_DIVIDER 5.546644154f
#endif

#ifndef BRIDGE_BAT_MAX_V
#define BRIDGE_BAT_MAX_V 12.6f
#endif

#ifndef BRIDGE_BAT_MIN_V
#define BRIDGE_BAT_MIN_V 9.3f
#endif

#ifndef BRIDGE_BAT_BLINK_V
#define BRIDGE_BAT_BLINK_V 9.0f
#endif

#ifndef BRIDGE_BAT_ALL_BLINK_V
#define BRIDGE_BAT_ALL_BLINK_V 8.8f
#endif

static Adafruit_NeoPixel statusStrip(BRIDGE_WS2815_COUNT, BRIDGE_WS2815_PIN, BRIDGE_WS2815_PIXEL_TYPE);

static uint32_t batteryMv = 0;
static float batteryV = 0.0f;
static uint8_t batteryRedCount = 0;
static bool batteryBlink = false;
static bool batteryAllBlink = false;
static bool blinkOn = true;
static uint32_t shutterFlashUntil = 0;
static bool stripInitialized = false;  // forcé à false par le callback de calibration


static float readBatteryVoltage(uint32_t* mvOut) {
    uint32_t mv = analogReadMilliVolts(BRIDGE_BAT_ADC_PIN);
    if (mvOut) {
        *mvOut = mv;
    }
    return (mv / 1000.0f) * BRIDGE_BAT_DIVIDER;
}

void bridgeNotifyShutter() {
    shutterFlashUntil = millis() + 500;
}

static bool shutterFlashActive() {
    return (int32_t)(millis() - shutterFlashUntil) < 0;
}

static void updateBatteryState(float voltage) {
    const float span = BRIDGE_BAT_MAX_V - BRIDGE_BAT_MIN_V;
    const float step = span / 3.0f;

    uint8_t redCount = 0;
    if (voltage < (BRIDGE_BAT_MAX_V - step)) {
        redCount = 1;
    }
    if (voltage < (BRIDGE_BAT_MAX_V - 2.0f * step)) {
        redCount = 2;
    }
    if (voltage <= BRIDGE_BAT_MIN_V) {
        redCount = 3;
    }

    batteryRedCount = redCount;
    batteryBlink = voltage < BRIDGE_BAT_BLINK_V;
    batteryAllBlink = voltage < BRIDGE_BAT_ALL_BLINK_V;
}


static void showBootRainbow(uint32_t durationMs, uint16_t stepMs) {
    if (statusStrip.numPixels() == 0) {
        return;
    }

    uint32_t start = millis();
    uint32_t hue = 0;

    while (millis() - start < durationMs) {
        for (uint16_t i = 0; i < statusStrip.numPixels(); ++i) {
            uint32_t pixelHue = hue + (i * 65536UL / statusStrip.numPixels());
            uint32_t color = statusStrip.gamma32(statusStrip.ColorHSV(pixelHue));
            statusStrip.setPixelColor(i, color);
        }
        statusStrip.show();
        hue += 512;
        delay(stepMs);
    }
}

static void onCalibrationActive(bool active) {
    if (active) {
        for (uint16_t i = 0; i < statusStrip.numPixels(); ++i) {
            statusStrip.setPixelColor(i, statusStrip.Color(64, 10, 30));  // rose
        }
        statusStrip.show();
    } else {
        stripInitialized = false;  // force un redessin complet à la fin de la calibration
    }
}

static void updateStatusStrip(bool bleConnected,
                              bool apClientConnected,
                              uint8_t batRedCount,
                              bool batBlink,
                              bool allBlink,
                              bool blinkState,
                              bool shutterFlash,
                              bool m1Off,
                              bool m2Off,
                              bool recording) {
    static bool lastBle = false;
    static bool lastAp  = false;
    static uint8_t lastBatRed = 0;
    static bool lastBatBlink = false;
    static bool lastAllBlink = false;
    static bool lastBlinkOn = false;
    static bool lastShutter = false;
    static bool lastM1Off = false;
    static bool lastM2Off = false;
    static bool lastRec  = false;

    if (stripInitialized && bleConnected == lastBle && apClientConnected == lastAp &&
        batRedCount == lastBatRed && batBlink == lastBatBlink &&
        allBlink == lastAllBlink && blinkState == lastBlinkOn &&
        shutterFlash == lastShutter &&
        m1Off == lastM1Off && m2Off == lastM2Off &&
        recording == lastRec) {
        return;
    }

    stripInitialized = true;
    lastBle = bleConnected;
    lastAp  = apClientConnected;
    lastBatRed = batRedCount;
    lastBatBlink = batBlink;
    lastAllBlink = allBlink;
    lastBlinkOn = blinkState;
    lastShutter = shutterFlash;
    lastM1Off = m1Off;
    lastM2Off = m2Off;
    lastRec  = recording;

    statusStrip.clear();

    if (allBlink) {
        if (blinkState) {
            for (uint16_t i = 0; i < statusStrip.numPixels(); ++i) {
                statusStrip.setPixelColor(i, statusStrip.Color(64, 0, 0));
            }
        }
        statusStrip.show();
        return;
    }

    const uint8_t bleR = bleConnected ? 0 : 64;
    const uint8_t bleG = bleConnected ? 64 : 0;
    statusStrip.setPixelColor(0, statusStrip.Color(bleR, bleG, 0));

    const uint8_t apR = apClientConnected ? 0 : 64;
    const uint8_t apG = apClientConnected ? 64 : 0;
    statusStrip.setPixelColor(1, statusStrip.Color(apR, apG, 0));

    // LED 2 : statut moteurs.  jaune = M1 stoppé, bleu = M2 stoppé,
    // rouge = les deux stoppés, éteinte = les deux actifs.
    if (m1Off && m2Off) {
        statusStrip.setPixelColor(2, statusStrip.Color(64,  0,  0));   // rouge
    } else if (m1Off) {
        statusStrip.setPixelColor(2, statusStrip.Color(64, 64,  0));   // jaune
    } else if (m2Off) {
        statusStrip.setPixelColor(2, statusStrip.Color( 0,  0, 64));   // bleu
    }
    // sinon : LED 2 reste éteinte (déjà fait par statusStrip.clear())

    if (statusStrip.numPixels() >= 3) {
        uint16_t batStart = statusStrip.numPixels() - 3;
        if (batBlink) {
            if (blinkState) {
                for (uint16_t i = 0; i < 3; ++i) {
                    statusStrip.setPixelColor(batStart + i, statusStrip.Color(64, 0, 0));
                }
            }
        } else {
            uint8_t clampedRed = min<uint8_t>(3, batRedCount);
            for (uint16_t i = 0; i < 3; ++i) {
                bool red = i >= (3 - clampedRed);
                uint8_t r = red ? 64 : 0;
                uint8_t g = red ? 0 : 64;
                statusStrip.setPixelColor(batStart + i, statusStrip.Color(r, g, 0));
            }
        }
    }

    // LED 3 : prioritaire = enregistrement video (rouge clignotant via
    // blinkState), sinon flash obturateur photo (blanc), sinon eteinte.
    if (statusStrip.numPixels() >= 4) {
        if (recording) {
            if (blinkState) statusStrip.setPixelColor(3, statusStrip.Color(64, 0, 0));
        } else if (shutterFlash) {
            statusStrip.setPixelColor(3, statusStrip.Color(64, 64, 64));
        }
    }

    statusStrip.show();
}

void setup() {
    Serial.begin(115200);
    delay(500);

    // NOTE: RGB_BUILTIN/LED_BUILTIN is GPIO 48 on this board, which is the same
    // pin as DRV_EN. Driving it would put the DRV8313 in an undefined state.
    // Status is shown on the WS2815 strip (GPIO 4) instead.

    statusStrip.begin();
    statusStrip.setBrightness(BRIDGE_WS2815_BRIGHTNESS);
    statusStrip.clear();
    statusStrip.show();

    showBootRainbow(1500, 40);

    // ── ADC2 init AVANT le FOC : la calibration des butées va lire les
    //    sondes courant pendant que le Wi-Fi n'est pas encore actif (ADC2
    //    100% fiable, cf. esp32_adc2_wifi.md).
    bridgeCurrentInit();

    bridgeFocSetup();
    bridgeFocSetCalCallback(onCalibrationActive);

    analogReadResolution(12);
    analogSetPinAttenuation(BRIDGE_BAT_ADC_PIN, ADC_11db);

    // ── LittleFS ──────────────────────────────
    if (!LittleFS.begin(true)) {
        Serial.println("[FS] LittleFS mount failed – formatting...");
        LittleFS.format();
        LittleFS.begin(false);
    }
    Serial.println("[FS] LittleFS mounted.");

    // ── Config ────────────────────────────────
    if (configLoad(cfg)) {
        Serial.println("[Config] Loaded from flash.");
    } else {
        Serial.println("[Config] Using defaults.");
    }
    Serial.printf("[Config] GoPro SSID: \"%s\"  Bridge SSID: \"%s\"\n",
                  cfg.gopro_ssid.c_str(), cfg.bridge_ssid.c_str());

    // ── WiFi AP+STA ───────────────────────────
    wifiStart(cfg);

    // ── BLE ───────────────────────────────────
    goproBLE.begin("GP");

    // ── HTTPS server only ─────────────────────
    if (!httpsStart(cfg)) {
        Serial.println("[HTTPS] Failed to start.");
    }

    Serial.printf("\n[Ready] Connect to WiFi \"%s\" then open http://192.168.4.1\n"
                  "         Install the cert, then use https://192.168.4.1\n\n",
                  cfg.bridge_ssid.c_str());

    // Lance le monitor périodique de surcourant maintenant que le Wi-Fi est
    // démarré (lectures avec retry pour encaisser le partage Wi-Fi/ADC2).
    bridgeCurrentStartMonitor();

    batteryV = readBatteryVoltage(&batteryMv);
    updateBatteryState(batteryV);
    updateStatusStrip(false, false, batteryRedCount, batteryBlink, batteryAllBlink, true, false,
                      false, false, false);
}

void loop() {
    // WiFi STA reconnect watchdog
    wifiWatchdog();

    bridgeFocLoop();

    // blinkOn toggle alimente : (1) blink batterie critique, (2) clignote rouge
    // LED 3 pendant un enregistrement video. Periode 500 ms pour le recording
    // (plus calme/cinema) - si batterie critique aussi, 300 ms l'emporte.
    static unsigned long blinkTs = 0;
    bool recording = goproBLE.isRecording();
    if (batteryBlink || batteryAllBlink) {
        if (millis() - blinkTs > 300) { blinkTs = millis(); blinkOn = !blinkOn; }
    } else if (recording) {
        if (millis() - blinkTs > 500) { blinkTs = millis(); blinkOn = !blinkOn; }
    } else {
        blinkOn = true;
    }

    static unsigned long stripTs = 0;
    if (millis() - stripTs > 200) {
        stripTs = millis();
        updateStatusStrip(goproBLE.isConnected(),
                  wifiApHasClients(),
                  batteryRedCount,
                  batteryBlink,
                  batteryAllBlink,
                  blinkOn,
                  shutterFlashActive(),
                  !bridgeFocIsMotorEnabled(1),
                  !bridgeFocIsMotorEnabled(2),
                  recording);
    }

    static unsigned long adcTs = 0;
    if (millis() - adcTs > 1000) {
        adcTs = millis();
        batteryV = readBatteryVoltage(&batteryMv);
        updateBatteryState(batteryV);
        // Serial.printf("[BAT] adc=%lumV v=%.2fV red=%u blink=%d all=%d\n",
        //               (unsigned long)batteryMv,
        //               batteryV,
        //               (unsigned)batteryRedCount,
        //               batteryBlink ? 1 : 0,
        //               batteryAllBlink ? 1 : 0);
    }

    // Heap watch : free = libre instantané, min = plus bas atteint depuis boot,
    // largest = plus gros bloc contigu (mbedTLS a besoin de ~30 ko contigus
    // par session TLS). Si largest tombe sous 30 ko -> ALLOC_FAILED en HTTPS.
    static unsigned long heapTs = 0;
    if (millis() - heapTs > 5000) {
        heapTs = millis();
        Serial.printf("[HEAP] free=%u  min=%u  largest=%u\n",
                      (unsigned)ESP.getFreeHeap(),
                      (unsigned)ESP.getMinFreeHeap(),
                      (unsigned)ESP.getMaxAllocHeap());
    }
}

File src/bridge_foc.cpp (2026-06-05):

#include "bridge_foc.h"
#include "bridge_ble.h"
#include "bridge_led.h"
#include "bridge_current.h"
#include <Arduino.h>
#include <SPI.h>
#include <Wire.h>
#include <SimpleFOC.h>
#include <Preferences.h>

// Pinout from src/main.cpp (custom DRV8313 board)
#define M1_IN1    14
#define M1_IN2    17
#define M1_IN3    18
#define M1_FAULT   1

#define M2_IN1    21
#define M2_IN2    38
#define M2_IN3    47
#define M2_FAULT   2

#define DRV_EN    48
#define PIN_MOSI  11
#define PIN_SCLK  12
#define PIN_MISO  13
#define ENC1_CS   10
#define ENC2_CS    8

const int POLE_PAIRS = 11;
const float SUPPLY_VOLTAGE = 12.0f;
const float VOLTAGE_LIMIT = 6.0f;

// Button behavior selectable at runtime: false = step on press, true = hold to move.
static bool button_hold_continuous = false;

bool bridgeFocGetButtonHoldContinuous() { return button_hold_continuous; }
void bridgeFocSetButtonHoldContinuous(bool hold) { button_hold_continuous = hold; }

BLDCMotor motor1(POLE_PAIRS);
BLDCMotor motor2(POLE_PAIRS);
BLDCDriver3PWM driver1(M1_IN1, M1_IN2, M1_IN3);
BLDCDriver3PWM driver2(M2_IN1, M2_IN2, M2_IN3);
MagneticSensorSPI sensor1(AS5048_SPI, ENC1_CS);
MagneticSensorSPI sensor2(AS5048_SPI, ENC2_CS);
SPIClass spiBus(HSPI);

float target1 = 0.0f;
float target2 = 0.0f;
bool verbose = false;
// Step pas-a-pas et vitesse continue : ajustables via /foc/step et /foc/speed.
// Vitesse continue (deg/s) = HOLD_STEP_DEG * 1000 / HOLD_STEP_MS (defaut 100 deg/s).
float TARGET_STEP_DEG = 7.0f;
float HOLD_STEP_DEG = 2.0f;
const uint32_t HOLD_STEP_MS = 20;
float bridgeFocGetStepDeg() { return TARGET_STEP_DEG; }
void  bridgeFocSetStepDeg(float v) {
  if (v < 0.5f) v = 0.5f;
  if (v > 45.0f) v = 45.0f;
  TARGET_STEP_DEG = v;
}
float bridgeFocGetHoldDegPerSec() { return HOLD_STEP_DEG * 1000.0f / (float)HOLD_STEP_MS; }
void  bridgeFocSetHoldDegPerSec(float dps) {
  if (dps < 5.0f)   dps = 5.0f;
  if (dps > 500.0f) dps = 500.0f;
  HOLD_STEP_DEG = dps * (float)HOLD_STEP_MS / 1000.0f;
}
bool run_m1 = true;
bool run_m2 = true;
bool motors_enabled = false;

// ── Soft-limits (calibration butées via sondes courant) ────────────────────
// Détection de butée : on rampe lentement le target, et un pic de courant
// sustained = on a tapé en mécanique. On note l'angle, on inverse, idem.
//
// Paramètres tunables :
#define CAL_RAMP_DEG_PER_TICK   0.5f      // 0.5° par tick = ~25°/s à 50 Hz
#define CAL_TICK_MS             20         // 50 Hz
#define CAL_END_STOP_RAW        500        // ~0.4 A : > stall normal mais << OCP driver
#define CAL_CONSEC_HITS         3          // 3 ticks = 60 ms de courant sustained
#define CAL_BACKOFF_MS          400        // pause avant de repartir dans l'autre sens
#define CAL_SAFETY_MARGIN_DEG   5.0f       // marge soft entre limite physique et logicielle
#define CAL_TIMEOUT_MS          30000U     // sécurité globale, abandon si on n'a pas fini
// Butées physiques mesurées (degrés, lectures AS5048 via SimpleFOC)
// Soft-limits = butée ± CAL_SAFETY_MARGIN_DEG, identique à la calibration auto.
#define CAL_DEFAULT_M1_LIM_NEG_DEG   251.0f
#define CAL_DEFAULT_M1_LIM_POS_DEG   320.0f
#define CAL_DEFAULT_M2_LIM_NEG_DEG  -345.0f
#define CAL_DEFAULT_M2_LIM_POS_DEG  -265.0f
#define CAL_HOLD_MS             3000U      // maintien des 4 boutons pour déclencher une calibration
#define CAL_ALL_MASK            0x55u      // bits P0|P2|P4|P6 du PCF8574 (M1+, M2+, M1−, M2−)
#define VEL_LIMIT_NORMAL        30.0f      // velocity_limit normal
#define VEL_LIMIT_RETURN        1.0f       // velocity_limit pendant un retour-en-zone (≈57°/s)

static bool  m1_cal_ok = false, m2_cal_ok = false;
static float m1_lim_neg = 0, m1_lim_pos = 0;     // butées physiques (rad)
static float m2_lim_neg = 0, m2_lim_pos = 0;
static float m1_soft_neg = 0, m1_soft_pos = 0;   // limites logicielles (rad)
static float m2_soft_neg = 0, m2_soft_pos = 0;
static bool  m1_returning = false, m2_returning = false;
static bool     cal_pending     = false;
static uint32_t cal_hold_since  = 0;
static bool     cal_hold_active = false;
static BridgeFocCalCallback s_cal_cb = nullptr;
void bridgeFocSetCalCallback(BridgeFocCalCallback cb) { s_cal_cb = cb; }

static float clampM1(float t) {
  if (!m1_cal_ok) return t;
  if (t > m1_soft_pos) return m1_soft_pos;
  if (t < m1_soft_neg) return m1_soft_neg;
  return t;
}
static float clampM2(float t) {
  if (!m2_cal_ok) return t;
  if (t > m2_soft_pos) return m2_soft_pos;
  if (t < m2_soft_neg) return m2_soft_neg;
  return t;
}

// ── Surveillance broche FAULT du DRV8313 ────────────────────────────────────
// nFAULT actif bas (overtemp / overcurrent / undervoltage). Le hardware filtre
// déjà ~1 ms via R19+C17. On exige FAULT_CONSECUTIVE lectures basses
// consécutives, échantillonnage à FAULT_CHECK_PERIOD_MS, puis on coupe le
// moteur concerné. Le latch est levé via bridgeFocEnableMotor() (m1on/m2on).
#define FAULT_CONSECUTIVE     3
#define FAULT_CHECK_PERIOD_MS 5

static int      m1_fault_streak   = 0;
static int      m2_fault_streak   = 0;
static bool     m1_fault_tripped  = false;
static bool     m2_fault_tripped  = false;
static uint32_t last_fault_check  = 0;

void stepTargetM1(float deg_step);
void stepTargetM2(float deg_step);

bool bridgeFocIsMotorEnabled(int idx) {
  if (!motors_enabled) return false;
  if (idx == 1) return run_m1;
  if (idx == 2) return run_m2;
  return false;
}

void bridgeFocDisableMotor(int idx) {
  if (idx == 1) {
    run_m1 = false;
    motor1.disable();
    Serial.println("[FOC] M1 disabled");
  } else if (idx == 2) {
    run_m2 = false;
    motor2.disable();
    Serial.println("[FOC] M2 disabled");
  }
}
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

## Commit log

2026-06-05 add .h files fix: calibration stopping too early resulting of one motor not going back in its middle position
    [bridge_current.cpp, bridge_foc.cpp]
2026-06-05 added CAD and Kicad files and updated README
    [Assemblage_ButtonV2.3MF, Assemblage_ButtonV2.SLDASM, Bearing_support.3MF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]
2026-06-05 added BOM
    [BOM.xlsx]
